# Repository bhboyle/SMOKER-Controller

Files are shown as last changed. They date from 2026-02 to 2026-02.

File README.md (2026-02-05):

# DIY Smoker Controller System

A dual-ESP32 based smart controller system for pellet or Gravity smokers, featuring a touchscreen display unit and WiFi-enabled web interface for remote monitoring and control. 

Some notes about the dual ESP32 design. I originally had planned to use just the display ESP32P4(with its ESP32-C6) however I found that the system lagged more than I was comfortable with and decided to add the ESP32-S3. This may have been my skills or something else. I also went with the ESP32-S3-N16R8 version for the web server allowing for a large filesystem to store smoker logs which I plan to use for "recipes." I also liked the OTA option for the web server given its going to be difficult to update once installed in the smokers housing. I don't expect to need to update the display ESP32-P4 now that it is only driving the display, fan and tach.

This system is not intended to less expensive than other options out in the aftermarket stores. Depending on where your buying the parts it would likely be around 80-100 dollars in parts assuming you have some of the essentials like screws and heat set inserts. With all the hardware testing I did it was notably more expensive than an existing product. However, now that it is done, I have exactly what I wanted, it is configurable and updatable in ways store bought options could never be. This has been a passion project that is now ready to be tested on my Masterbuilt Gravity smoker.

## ⚠️ Safety Warning

**🔥🔥This project involves controlling and working with fire. Use at your own risk.🔥🔥**

**IMPORTANT:**
- This software and design is provided as-is with no guarantees of safety or reliability
- You assume all responsibility for any damage, injury, or loss resulting from the use of this project
- Always follow proper fire safety protocols and never leave your smoker unattended
- Ensure your hardware setup meets all local electrical and fire safety codes
- The authors are not responsible for any accidents, fires, property damage, or injuries

**By using this project, you acknowledge these risks and agree to take full responsibility.**

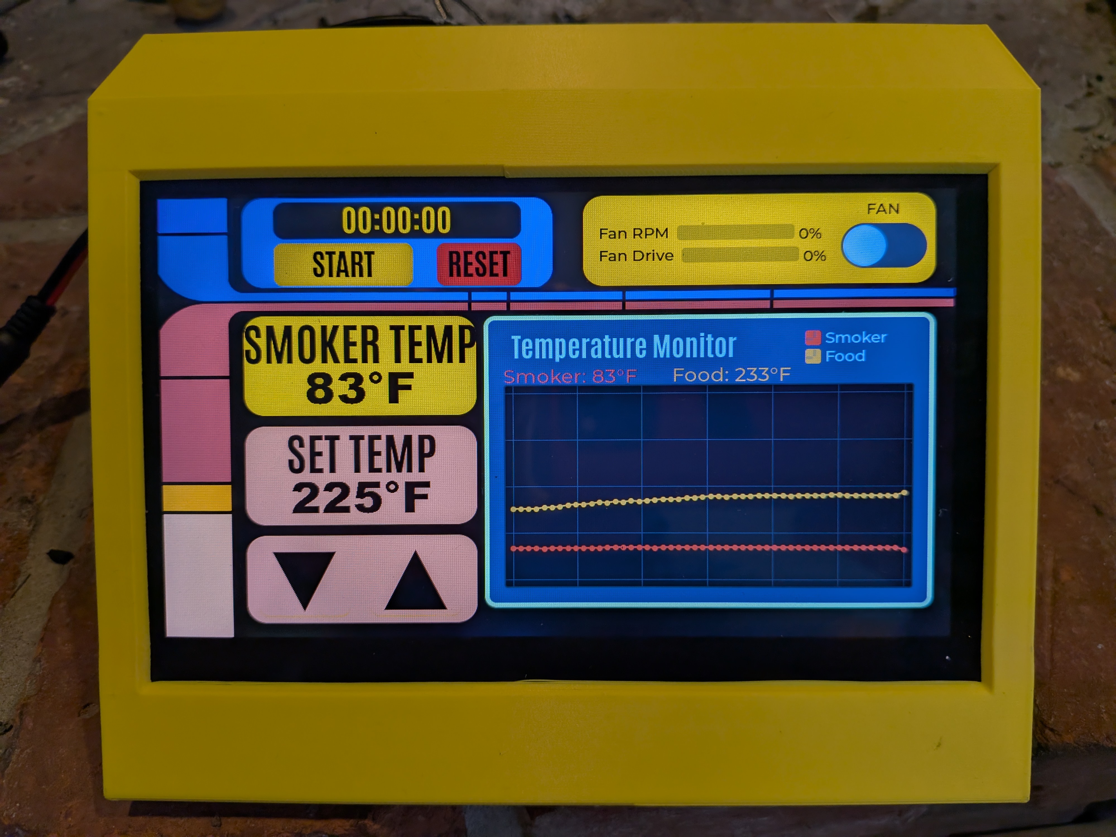
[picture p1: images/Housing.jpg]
Image of controller





## System Overview

This project consists of two ESP32 microcontrollers working together to provide comprehensive smoker monitoring and control:

```
┌─────────────────────────────────────────────────────────────────────────────┐
│                        SMOKER CONTROLLER SYSTEM                             │
├─────────────────────────────────────────────────────────────────────────────┤
│                                                                             │
│   ┌─────────────────────┐         UART           ┌─────────────────────┐    │
│   │    ESP32-P4         │◄──────────────────────►│    ESP32-S3         │    │
│   │  Display Controller │    (Bidirectional)     │    Web Server       │    │
│   └─────────────────────┘                        └─────────────────────┘    │
│            │                                              │                 │
│            │                                              │                 │
│            ▼                                              ▼                 │
│   ┌─────────────────────┐                        ┌─────────────────────┐    │
│   │ 1024x600 LCD        │                        │ WiFi / Web UI       │    │
│   │ Touchscreen         │                        │ MAX6675 Sensors     │    │
│   │ Fan PWM Control     │                        │ OTA Updates         │    │
│   │ PID Controller      │                        │ Temperature Sensing │    │
│   └─────────────────────┘                        └─────────────────────┘    │
│                                                                             │
└─────────────────────────────────────────────────────────────────────────────┘
```

### Build environment.
It is worth noting that I used the excelent [Arduinio Maker Workshop](https://github.com/thelastoutpostworkshop/arduino-maker-workshop) VSCode extension for these projects. Each one of the two projects included here includes the build profiles so assuming you use the same hardware you can comnpile it without any issues with libraries.

### ESP32-P4: Display Controller
**Location:** [DisplayControler/](DisplayControler/)

The display unit(JC1060P470) provides the physical user interface:
- 1024x600 LCD touchscreen with GT911 capacitive touch
- PID-based temperature control algorithm
- PWM fan control with RPM feedback
  - it is worth noting that the system does not have to drive a fan. With some minor changes this system could drive a servo instead of a fan to control an ball valve. This would allow you to control passive fire systems like other Gravity Smokers.
- Real-time temperature charting
- Cook timer functionality
- Safety watchdog (auto-disables fan if communication lost)
- [Ordered from here](https://www.aliexpress.com/p/tesla-landing/index.html?productId=1005009348846335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)

### ESP32-S3: Web Server
**Location:** [SmokerWebServer/](SmokerWebServer/)

The web server module handles connectivity and sensing:
- WiFi connectivity with AP fallback for setup
- Mobile-friendly web dashboard
- MAX6675 thermocouple interfaces (smoker + food probes)
- WebSocket for real-time updates
- REST API for integration
- OTA (Over-The-Air) firmware updates
- mDNS support (`smoker.local`)
- [Example here from Amazon](https://www.amazon.ca/HiLetgo-ESP32-S3-ESP32-S3-DevKit-Bluetooth-Development/dp/B0CDWXWXCG)

## Features

### Temperature Monitoring
- Dual K-type thermocouple inputs (smoker chamber + food probe)
- Calibration offsets (-50 to +50°F) stored in non-volatile memory
- 2-hour temperature history with graphing both on display and webpage
- Real-time updates via WebSocket (1-second refresh)

### Temperature Control
- PID algorithm for precise temperature maintenance
- Configurable PID parameters (Kp, Ki, Kd) from the webpage
- Fan-based airflow control with RPM feedback
- Target temperature range: 150-500°F

### User Interface
- **Local:** 1024x600 touchscreen with intuitive controls
- **LCARS** interface. I'm a Trekie so I use the Star Trek TNG LCARS as my inspiration for the user interface on the touch screen 
- **Remote:** Responsive web interface accessible from any device
- Both interfaces show:
  - Current smoker and food temperatures
  - Target temperature with adjustment controls
  - Fan status, RPM, and PWM percentage
  - Cook timer with start/stop/reset

### Safety Features
- Temperature watchdog: Fan auto-disables if no data received for 10 seconds
- PID output limits for controlled operation
- Visual "NO LINK" indicator on display when communication is lost with web server.

## Hardware Requirements

### Components List

| Component | Quantity | Purpose |
|---|---|---|
| [ESP32-P4 Development Board](https://www.aliexpress.com/p/tesla-landing/index.html?productId=1005009348846335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) | 1 | Display controller |
| [ESP32-S3-DevKitC-1 (N16R8)](https://www.amazon.ca/HiLetgo-ESP32-S3-ESP32-S3-DevKit-Bluetooth-Development/dp/B0CDWXWXCG) | 1 | Web server, WiFi, sensors |
| 1024x600 LCD (JD9165 driver) | 1 | Main display (Integrated) |
| GT911 Touch Controller | 1 | Touchscreen input (Integrated)|
| [MAX6675 Thermocouple Module](https://www.amazon.ca/dp/B0DDCGDLGJ?ref=ppx_yo2ov_dt_b_fed_asin_title)  | 2 | Temperature sensing |
| K-type Thermocouple | 1 | Smoker probe (Just use prone that came with the module) |
| [K-type Thermocouple](https://www.amazon.ca/dp/B0BJB1JZKQ) | 1 | food probe |
| 4-wire PWM Fan | 1 | Airflow control |
| [14pin .5mm FPC connector](https://www.amazon.ca/dp/B0CLH5FWKN?ref=ppx_yo2ov_dt_b_fed_asin_title&th=1) | 1 | communication to Web server |
| [Flexible flat cable](https://www.amazon.ca/dp/B07RWF4FF6?ref=ppx_yo2ov_dt_b_fed_asin_title) | 1 | connection with Web server |

### Pin Connections

#### ESP32-P4 (Display Controller)
| Function | GPIO |
|---|---|
| Fan PWM Output | 28 |
| Fan Tachometer Input | 29 |
| Serial TX (to S3) | 34 |
| Serial RX (from S3)  | 33 |

#### ESP32-S3 (Web Server)
| Function | GPIO |
|---|---|
| SPI CLK (MAX6675) | 12 |
| SPI MISO (MAX6675)  | 13 |
| Smoker Probe CS | 10 |
| Food Probe CS | 11 |
| Serial TX (to P4) | 17 |
| Serial RX (from P4) | 18 |

### Wiring Diagram

```
ESP32-S3                                ESP32-P4
┌─────────┐                            ┌─────────┐
│  GPIO17 ├───── TX ──────────────────►│ GPIO33  │ RX
│  GPIO18 │◄──── RX ───────────────────┤ GPIO34  │ TX
│         │                            │         │
│  GPIO12 ├──── CLK ──┐                │ GPIO28  ├──── PWM ────► Fan
│  GPIO13 ├──── MISO ─┤                │ GPIO29  │◄─── TACH ───┤
│  GPIO10 ├──── CS1 ──┼──► MAX6675s    └─────────┘
│  GPIO11 ├──── CS2 ──┘
│         │ 
└─────────┘ 

```

## Serial Communication Protocol

The two ESP32s communicate via UART using a simple text-based protocol:

### ESP32-S3 → ESP32-P4
```
TEMPS:smokerTemp,foodTemp              # Temperature readings (periodic)
CMD:SET_TEMP:225                       # Set target temperature
CMD:FAN:ON / CMD:FAN:OFF               # Fan control
CMD:TIMER:START / STOP / RESET         # Timer control
CMD:PID:Kp:Ki:Kd                       # Update PID parameters
CMD:GET_CONFIG                         # Request configuration
```

### ESP32-P4 → ESP32-S3
```
DATA:smokerTemp,foodTemp,setTemp,rpm,pwm,fanOn,timerMs,Kp,Ki,Kd
CONFIG:dispInterval,chartInterval,buttonHold,swapInterval,fadeDuration,Kp,Ki,Kd
```

## PID Tuning:
I used [this page](https://www.compuphase.com/electronics/reflowsolderprofiles.htm#_) to help me with the PID tuning. 
It help me know which numbers to change and how. I started with a P value of 20 and zero for both I and D. This worked fairly well but through iterative testing I settled on P=7 I=.01 and D=.2 Your setup may be different but the page above would help you alot. 

## Installation
I used the Arduino Maker Workshop plugin for VSCode so the Sketch.yaml file in both project folders contians the library data and versions so there should be no conflicts when building.

## Initial Setup

### WiFi Configuration

1. On first boot, the ESP32-S3 creates an access point:
   - **SSID:** `SmokerSetup`
   - **Password:** `smoker123`
   - **IP:** `192.168.4.1`

2. Connect to the network and open `http://192.168.4.1`

3. Enter your WiFi credentials and save

4. The device restarts and connects to your network

### Accessing the Web Interface

After WiFi setup:
- **mDNS:** `http://smoker.local`
- **IP Address:** Check serial monitor or router DHCP list

## Usage

### Local (Touchscreen)
- **Temperature:** Tap UP/DOWN to adjust target, display alternates between smoker and food temps
- **Fan:** Toggle ON/OFF switch
- **Timer:** START/STOP and RESET buttons

### Remote (Web Interface)
- Navigate to `http://smoker.local`
- All controls mirror the touchscreen interface
- View 2-hour temperature history chart
- Adjust calibration offsets in Settings
- Tune PID parameters if needed
- Record, edit and save smoking sessions in database
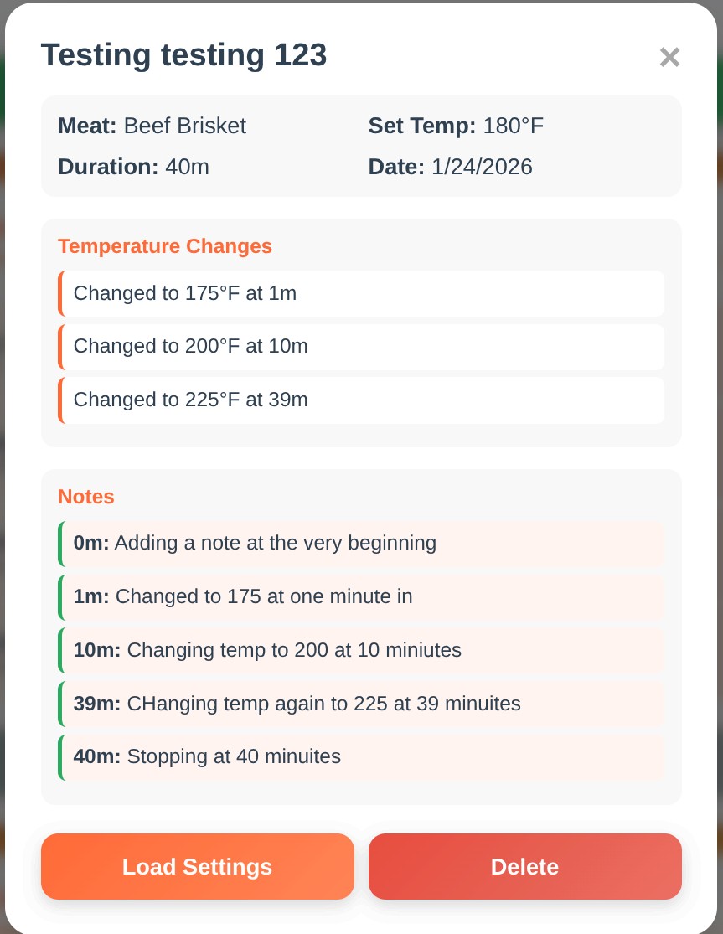
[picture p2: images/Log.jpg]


### OTA Updates
1. Navigate to `http://smoker.local/update`
2. Upload new firmware binary
3. Device restarts automatically

## API Reference

### REST Endpoints
| Endpoint | Method | Description |
|---|---|---|
| `/` | GET | Web dashboard |
| `/api/state` | GET | Current state (JSON) |
| `/api/command` | POST | Send command |
| `/api/calibration` | GET/POST | Calibration offsets  |
| `/wifi/status` | GET | WiFi status |
| `/wifi` | POST | Configure WiFi |
| `/update` | GET | OTA update page |

### WebSocket
Connect to `/ws` for real-time state updates at 1Hz.

## Project Structure

```
SMOKER Build/
├── README.md                              # This file
├── 5-Schematic/                           # Hardware schematics of display board
│   ├── 1_PWR.png
│   ├── 2_LCD.png
│   ├── 3_ESP32-P4.png
│   ├── 4_CONN.png
│   ├── 5_ESP32-C6.png
│   ├── 6_USB.png
│   └── 7_CODEC.png
├── DisplayControler/                       # ESP32-P4 Display Controller
│   ├── DisplayControler.ino
│   ├── pins_config.h
│   ├── style.h
│   ├── lv_conf.h
│   └── src/
│       ├── lcd/                           # LCD drivers
│       └── touch/                         # Touch drivers
└── SmokerWebServer/                       # ESP32-S3 Web Server
    ├── partitions.csv                     # ESP32 partition layout 
    ├── SmokerWebServer.ino
    ├── README.md
    └── (web interface files)
    
```

## Configuration Defaults

### PID Parameters
| Parameter | Default |
|---|---|
| Kp | 7.0 |
| Ki | 0.0 |
| Kd | 0.2 |

### Temperature Limits
| Setting | Value |
|---|---|
| Minimum | 150°F |
| Maximum | 500°F |
| Default | 225°F |

### Timing
| Setting | Default |
|---|---|
| Display Update | 500ms |
| Chart Update | 60 seconds |
| WebSocket Update | 1 second |
| Watchdog Timeout | 10 seconds |

## Troubleshooting

### Display shows "NO LINK"
- Check UART wiring between ESP32-P4 and ESP32-S3
- Verify TX connects to RX and vice versa
- Ensure both boards are powered

### Temperature shows -999
- Check MAX6675 wiring (CS, CLK, MISO)
- Verify thermocouple connections
- Check for open circuit in thermocouple

### Cannot connect to web interface
- Verify ESP32-S3 is connected to WiFi (check serial output)
- Try IP address instead of mDNS
- Ensure you're on the same network

### Fan not responding
- Check PWM wiring to GPIO 28 on ESP32-P4
- Verify fan receives proper power
- Check tachometer feedback wiring

## License

This project is licensed under the MIT License.

## Acknowledgments

- ESP32 Arduino Core developers
- LVGL graphics library team
- PID library developer
- AsyncWebServer library maintainers
- ElegantOTA for OTA updates
- Created with assistance from Claude (Anthropic)

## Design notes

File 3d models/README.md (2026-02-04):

I used a Bamblu labs P1S for my prints. I printed the housing on its back and required supports for the saids as well as the bottom of the display side. With out the supports the side tended to lean while being printed.

The template file is to be used to drill mounting holes if necessary.

The PCB for the second ESP32 the S3 and the MAX7765 among other things was fabricated on a perf board. The PCB mounting model is for attaching the two boards together. The perf board I used was [this one](https://www.amazon.ca/dp/B07Y3DVM1W?ref=ppx_yo2ov_dt_b_fed_asin_title&th=1).

I added some electrical tape on the under side of the retainer clips to act as padding. Not totally necessary but it seemed like a good idea to me.

The "Smoker Housing.f3d" file is the Fusion file for all compoments. With that you can make any changes you might need.

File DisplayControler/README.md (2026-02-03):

# Smoker Controller - Display Unit

An ESP32-P4 based touchscreen controller for monitoring and controlling a smoker. This unit provides the user interface with a 1024x600 LCD display and communicates with a separate ESP32-S3 web server module that handles temperature sensors and WiFi connectivity.

## Features

- **PID Temperature Control**: Maintains smoker temperature using a fan-based airflow control system
- **Dual Temperature Monitoring**: Displays both smoker chamber and food probe temperatures
- **Touchscreen Interface**: 1024x600 LCD with GT911 capacitive touch
- **Real-time Temperature Chart**: Graphical display of temperature history over time
- **Cook Timer**: Start/stop/reset timer for tracking cook duration
- **Fan Control**: Manual on/off control with RPM and drive percentage displays
- **Configurable Settings**: PID tuning parameters, display intervals, and UI settings stored in NVS (non-volatile storage)
- **Safety Watchdog**: Automatically disables fan if temperature data is not received within 10 seconds




## Hardware Requirements

### Display Controller (This Unit)
- **MCU**: ESP32-P4
- [Device was ordred from here](https://www.aliexpress.com/p/tesla-landing/index.html?productId=1005009348846335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)
- **Display**: 1024x600 LCD with JD9165 driver
- **Touch**: GT911 capacitive touch controller
- **Fan Output**: PWM on GPIO 28
- **Tachometer Input**: GPIO 29 (fan RPM feedback)
- **Serial Communication**: UART1 on GPIO 33 (RX) / GPIO 34 (TX)

### Web Server (Separate ESP32-S3 Module)
- Handles MAX6675 thermocouple interfaces
- Provides WiFi web interface
- Sends temperature data via serial: `TEMPS:smokerTemp,foodTemp`

## Pin Configuration

| Function | GPIO |
|---|---|
| LCD Reset | 27 |
| LCD Backlight  | 23 |
| Touch SDA | 7 |
| Touch SCL | 8 |
| Fan PWM | 28 |
| Fan Tachometer | 29 |
| Web Serial RX  | 33 |
| Web Serial TX  | 34 |

## Serial Protocol

### Messages FROM Web Server (ESP32-S3)
```
TEMPS:smokerTemp,foodTemp          # Temperature data (sent periodically)
CMD:SET_TEMP:225                   # Set target temperature
CMD:FAN:ON / CMD:FAN:OFF           # Control fan
CMD:TIMER:START/STOP/RESET         # Control timer
CMD:PID:Kp:Ki:Kd                   # Update PID tuning
CMD:DISPLAY_INT:500                # Set display update interval (ms)
CMD:CHART_INT:60000                # Set chart update interval (ms)
CMD:HOLD_TIME:5000                 # Button hold time before swap (ms)
CMD:SWAP_INT:2000                  # Container swap interval (ms)
CMD:FADE_DUR:100                   # Animation fade duration (ms)
CMD:GET_CONFIG                     # Request current configuration
```

### Messages TO Web Server (ESP32-S3)
```
DATA:smokerTemp,foodTemp,setTemp,rpm,pwm,fanOn,timerMs,Kp,Ki,Kd
CONFIG:dispInterval,chartInterval,buttonHold,swapInterval,fadeDuration,Kp,Ki,Kd
```

## Configuration Parameters

### PID Defaults
| Parameter | Default Value |
|---|---|
| Kp | 7.0 |
| Ki | 0.0 |
| Kd | 0.2 |

### Temperature Limits
| Setting | Value |
|---|---|
| Minimum Temp | 150°F |
| Maximum Temp | 500°F |
| Startup Temp | 225°F |

### Timing Defaults
| Setting | Default |
|---|---|
| Display Update | 500ms |
| Chart Update | 60000ms (1 min)  |
| Serial Update | 500ms |
| Watchdog Timeout | 10000ms (10 sec) |

## User Interface

The display is organized into several sections:

1. **Timer Section** (top-left): Displays elapsed cook time with START/STOP and RESET buttons
2. **Temperature Display** (left-center): Alternates between Actual Temp and Food Temp with cross-fade animation
3. **Set Temperature** (left-lower): Shows target temperature with UP/DOWN adjustment buttons
4. **Fan Control** (top-right): ON/OFF switch with RPM and Drive percentage bars
5. **Temperature Chart** (right): Real-time graph showing smoker (red) and food (orange) temperature trends

## Dependencies

- [LVGL](https://lvgl.io/) - Light and Versatile Graphics Library (v9.x)
- [PID_v1](https://github.com/br3ttb/Arduino-PID-Library) - Arduino PID Library
- ESP32 Arduino Core with Preferences library

## Building

This project is designed for the Arduino IDE or VSCode with the Arduino Maker Workshop with ESP32-P4 board support.

1. Install ESP32 board support (ESP32-P4 variant)
2. Install required libraries (LVGL, PID_v1)
3. Configure `lv_conf.h` for your display settings
4. Upload to ESP32-P4
5. Thsi display is configured for the resolution of the device I ordered. If your has a different resolution you will have to adjust things considerably.

## File Structure

```
DisplayControler/
├── DisplayControler.ino   # Main application
├── pins_config.h                          # GPIO pin definitions
├── style.h                                # LVGL style definitions
├── lv_conf.h                              # LVGL configuration
├── src/
│   ├── lcd/
│   │   ├── jd9165_lcd.cpp/.h              # LCD driver wrapper
│   │   └── esp_lcd_jd9165.c/.h            # Low-level LCD driver
│   └── touch/
│       ├── gt911_touch.cpp/.h             # Touch driver wrapper
│       ├── esp_lcd_touch_gt911.c/.h       # GT911 touch driver
│       └── esp_lcd_touch.c/.h             # Touch abstraction layer
└── *.c                                    # Custom fonts (Antonio, Arial)
```

## Safety Features

- **Temperature Watchdog**: If no temperature data is received from the ESP32-S3 for 10 seconds, the fan is automatically disabled to prevent uncontrolled heating
- **PID Output Limits**: Maximum fan PWM is capped at 255 but could be reduced in the code if there is a need to set lower limits. For example if you used a much more powerful fan you may want to reduce its upper limit.
- **Connection Status**: Display shows "NO LINK" when communication with the temperature sensor module is lost

## License

This project is for personal/educational use.

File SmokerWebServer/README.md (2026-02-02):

# Smoker Web Server - ESP32-S3

A web-based control and monitoring system for a pellet smoker, running on ESP32-S3. This firmware provides a mobile-friendly web interface for monitoring and controlling your smoker remotely.




## Overview

This project is the web server component of a two-board smoker controller system:
- **ESP32-S3** (this project): Handles WiFi, web interface, and temperature sensing
- **ESP32-P4** (display controller): Handles the physical display, fan control, and PID regulation

The ESP32-S3 reads temperatures from MAX6675 thermocouple sensors and sends them to the display controller, while also providing a responsive web dashboard for remote monitoring and control.

## Features

- **Real-time Monitoring**
  - Smoker temperature display
  - Food probe temperature display
  - Fan RPM and PWM output visualization
  - Cook timer with start/stop/reset controls
  - 2-hour temperature history chart

- **Remote Control**
  - Set target temperature
  - Toggle fan on/off
  - Adjust PID parameters (Kp, Ki, Kd)
  - Timer controls

- **Temperature Calibration**
  - Adjustable offset for smoker probe (-50 to +50°F)
  - Adjustable offset for food probe (-50 to +50°F)
  - Calibration values stored in NVram (persistent across power cycles)

- **Connectivity**
  - WiFi with AP fallback mode for initial setup
  - mDNS support (access via `smoker.local`)
  - WebSocket for real-time updates (1-second refresh)
  - REST API for integration

- **System**
  - OTA (Over-The-Air) firmware updates via ElegantOTA
  - Persistent settings stored in NVram
  - Mobile-friendly responsive web design

## Hardware Requirements

### Main Components
- **ESP32-S3-DevKitC-1** (N16R8 configuration)
  - 16MB Flash
  - 8MB PSRAM
- **2x MAX6675** thermocouple amplifier modules
- **K-type thermocouples** for smoker and food probes
- **ESP32-P4** display controller (separate board)

### Pin Configuration

| Function | GPIO Pin |
|---|---|
| SPI CLK (MAX6675)  | GPIO 12  |
| SPI MISO (MAX6675) | GPIO 13  |
| Smoker Probe CS | GPIO 10  | 
| Food Probe CS | GPIO 11  |
| Controller TX | GPIO 17  |
| Controller RX | GPIO 18  |

## Installation

### Building with Arduino IDE
1. Install ESP32 board support via Board Manager
2. Select "ESP32S3 Dev Module" as the board
3. Configure Flash Size: 16MB
4. Open `SmokerWebServer.ino` and upload

## Initial Setup

### WiFi Configuration

On first boot (or when no WiFi credentials are stored), the ESP32-S3 creates an access point:

| Setting | Value |
|---|---|
| SSID | `SmokerSetup` |
| Password | `smoker123` |
| IP Address | `192.168.4.1` |

1. Connect to the `SmokerSetup` WiFi network
2. Open a browser and navigate to `http://192.168.4.1`
3. Expand the "WiFi Settings" section
4. Enter your WiFi credentials and hostname
5. Click "Save & Connect"

The device will restart and connect to your network.

### Accessing the Dashboard

After WiFi configuration:
- **mDNS**: `http://smoker.local` (or your custom hostname)
- **IP Address**: Check your router or serial monitor for the assigned IP

## Web Interface

### Temperature Display
Shows current readings for:
- **Smoker**: Internal smoker temperature
- **Food**: Food probe temperature
- **Set Temp**: Target temperature

### Controls
- **Set Temperature**: Use arrow buttons to adjust, then click "Set Temp"
- **Fan Control**: Toggle switch to enable/disable the fan
- **RPM/PWM Bars**: Visual indicators of fan speed and duty cycle

### Timer
- **Start/Stop**: Toggle the cook timer
- **Reset**: Reset timer to 00:00:00

### Temperature History
A 2-hour rolling chart showing smoker and food temperatures, updated every 2 minutes.

### Advanced Settings

#### Temperature Calibration
Adjust probe offsets to correct for sensor inaccuracies:
- **Positive values**: Add degrees (if sensor reads low)
- **Negative values**: Subtract degrees (if sensor reads high)
- Range: -50°F to +50°F
- Values are saved to NVram and persist across reboots

#### PID Settings
Fine-tune the temperature control algorithm:
- **Kp**: Proportional gain (default: 7.0)
- **Ki**: Integral gain (default: 0.0)
- **Kd**: Derivative gain (default: 0.2)

### WiFi Settings
Change WiFi network or hostname without reflashing.

## API Reference

### REST Endpoints

| Endpoint | Method | Description |
|---|---|---|
| `/` | GET | Main web dashboard |
| `/api/state` | GET | Current smoker state (JSON)  |
| `/api/command` | POST | Send command to controller |
| `/api/calibration` | GET | Get calibration offsets |
| `/api/calibration` | POST | Set calibration offsets |
| `/wifi/status` | GET | WiFi connection status | 
| `/wifi` | POST | Configure WiFi settings |
| `/update` | GET | OTA update page (ElegantOTA) |

### WebSocket

Connect to `/ws` for real-time state updates.

**State JSON Format:**
```json
{
  "controllerConnected": true,
  "smokerTemp": 225,
  "foodTemp": 145,
  "setTemp": 225,
  "rpm": 1500,
  "pwm": 128,
  "fanOn": true,
  "timerMs": 3600000,
  "Kp": 7.0,
  "Ki": 0.0,
  "Kd": 0.2,
  "smokerOffset": 0,
  "foodOffset": -5,
  "smokerHistory": [220, 222, 225, ...],
  "foodHistory": [140, 142, 145, ...],
  "historyCount": 30
}
```

### Command Format

Send commands via WebSocket or POST to `/api/command`:
```json
{"command": "SET_TEMP:250"}
{"command": "FAN:ON"}
{"command": "FAN:OFF"}
{"command": "TIMER:START"}
{"command": "TIMER:RESET"}
{"command": "PID:7.0:0.0:0.2"}
{"command": "GET_CONFIG"}
```

## Serial Protocol

Communication with the ESP32-P4 display controller:

| Direction | Format | Example |
|---|---|---|
| To Controller | `CMD:command` | `CMD:SET_TEMP:250` |
| To Controller | `TEMPS:smoker,food` | `TEMPS:225,145` |
| From Controller | `DATA:s,f,set,rpm,pwm,fan,timer,Kp,Ki,Kd` | `DATA:-1,-1,225,1500,128,1,3600000,7.0,0.0,0.2` |

**Note:** The display controller sends `-1` for temperature values since the ESP32-S3 reads them locally.

## Partition Layout

Custom partition table optimized for OTA updates and data storage:

| Partition | Size  | Purpose |
|---|---|---|
| NVS | 24KB  | WiFi credentials, calibration, preferences |
| PHY_INIT  | 4KB | WiFi calibration data |
| OTA Data  | 8KB | Tracks active app partition |
| App0 | 3MB | Primary application |
| App1 | 3MB | OTA update partition |
| LittleFS  | 9.8MB | Future database storage |
| Coredump  | 64KB  | Crash debugging |

## OTA Updates

1. Navigate to `http://smoker.local/update`
2. Select the new firmware `.bin` file
3. Click "Update"
4. Wait for the device to restart

## Troubleshooting

### Cannot connect to WiFi
- Ensure credentials are correct
- Check if the network is 2.4GHz (ESP32 doesn't support 5GHz)
- Try resetting by erasing flash and reconfiguring

### Temperature reads -999
- Check thermocouple connections
- Verify MAX6675 wiring (CS, CLK, MISO pins)
- Ensure thermocouples are not open circuit

### Web interface not updating
- Check WebSocket connection status
- Verify the ESP32 is connected to WiFi
- Try refreshing the page

### Controller shows "Not Connected"
- Check serial connection between ESP32-S3 and P4
- Verify TX/RX pins are correctly wired (TX to RX, RX to TX)
- Ensure both boards are powered

## Dependencies

- [ESPAsyncWebServer](https://github.com/me-no-dev/ESPAsyncWebServer)
- [AsyncTCP](https://github.com/me-no-dev/AsyncTCP)
- [ArduinoJson](https://arduinojson.org/)
- [ElegantOTA](https://github.com/ayushsharma82/ElegantOTA)
- ESP32 Preferences library (built-in)

## Contributing

Contributions are welcome! Please feel free to submit a Pull Request.

## License

This project is licensed under the MIT License - see the [LICENSE](LICENSE) file for details.

## Author

Created with assistance from Claude (Anthropic)

## Acknowledgments

- ESP32 Arduino Core developers
- AsyncWebServer library maintainers
- ElegantOTA for simple OTA updates

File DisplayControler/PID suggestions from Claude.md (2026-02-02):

PID Tuning Suggestions for Smoker Temperature Control
Based on your current values (P=7, I=0, D=0.2), here are some suggestions:

Current Issues Analysis
I=0 (No Integral): Without an integral term, you'll likely have steady-state error - the temperature will settle somewhere near but not exactly at your setpoint. This makes it hard to maintain temperature within 5°F.

D=0.2 is relatively low: For thermal systems which respond slowly, a higher derivative term can help anticipate changes and reduce overshoot.

Recommended Starting Points
Option 1: Conservative Tuning (Minimal Overshoot Priority)

P = 5-6    (slightly lower to reduce overshoot)
I = 0.01-0.05  (small value to eliminate steady-state error)
D = 0.5-1.0    (higher to dampen oscillations)
Option 2: Responsive Tuning (Faster to Setpoint)

P = 7-8    (keep similar)
I = 0.02-0.1   (moderate integral)
D = 1.0-2.0    (more aggressive dampening)
Key Principles for Thermal Systems
Parameter	Effect	Smoker Considerations
P (Proportional)	Determines response strength	Too high = overshoot; too low = slow response
I (Integral)	Eliminates steady-state error	Essential for holding ±5°F; start very small
D (Derivative)	Dampens oscillations	Thermal mass means changes are slow; higher D helps
Tuning Process
Add a small I term first (try 0.02) - this will help eliminate the offset between actual and target temp

Increase D (try 0.5-1.0) - this will help prevent overshoot as you approach setpoint

Adjust P if needed - if you still overshoot, reduce P slightly

Watch for integral windup - if your code doesn't limit integral accumulation, the I term can cause large overshoots after long periods below setpoint

Suggested Starting Point

P = 6
I = 0.03
D = 0.8
This should give you smooth approach to setpoint with minimal overshoot, and the integral term will work to keep you within your ±5°F band.

Would you like me to look at your actual PID implementation code to see if there are any other factors (like integral windup protection, output clamping, or sample rate) that might affect tuning?

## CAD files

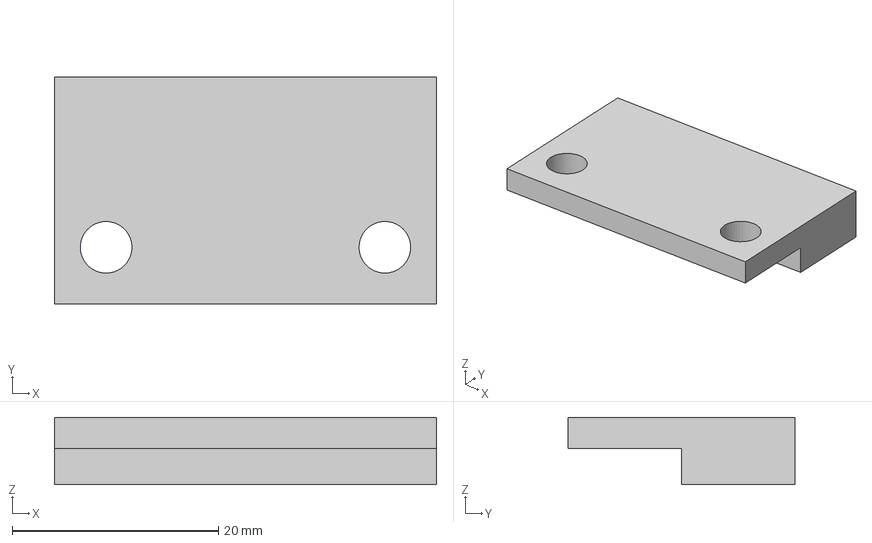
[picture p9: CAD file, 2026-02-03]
3d models/Small Clip.3mf
37.0 x 22.0 x 6.50 mm

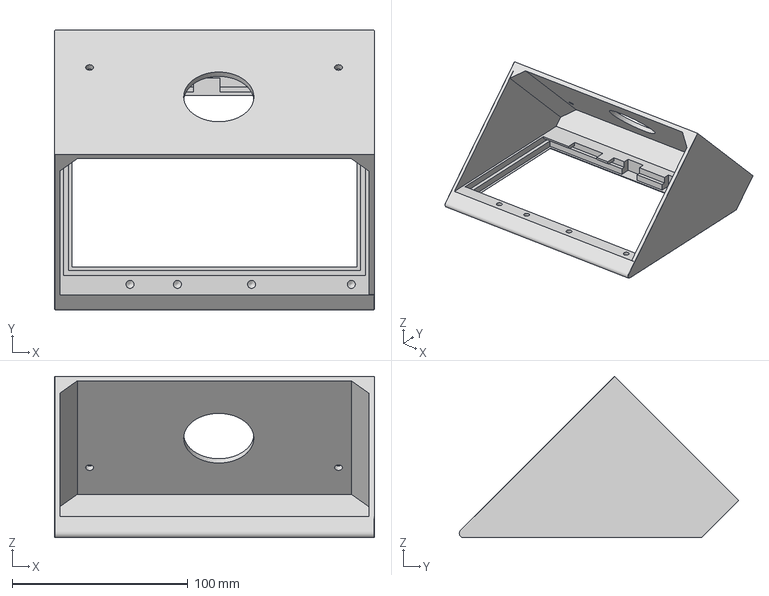
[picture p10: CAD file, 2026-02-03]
3d models/Housing.3mf
182.2 x 159.2 x 91.9 mm

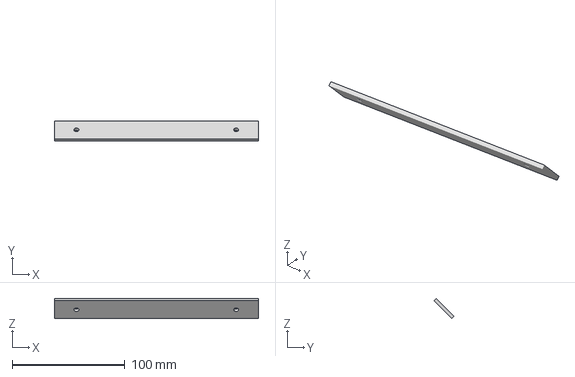
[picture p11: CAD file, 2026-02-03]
3d models/Template.3mf
180.9 x 18.0 x 18.0 mm

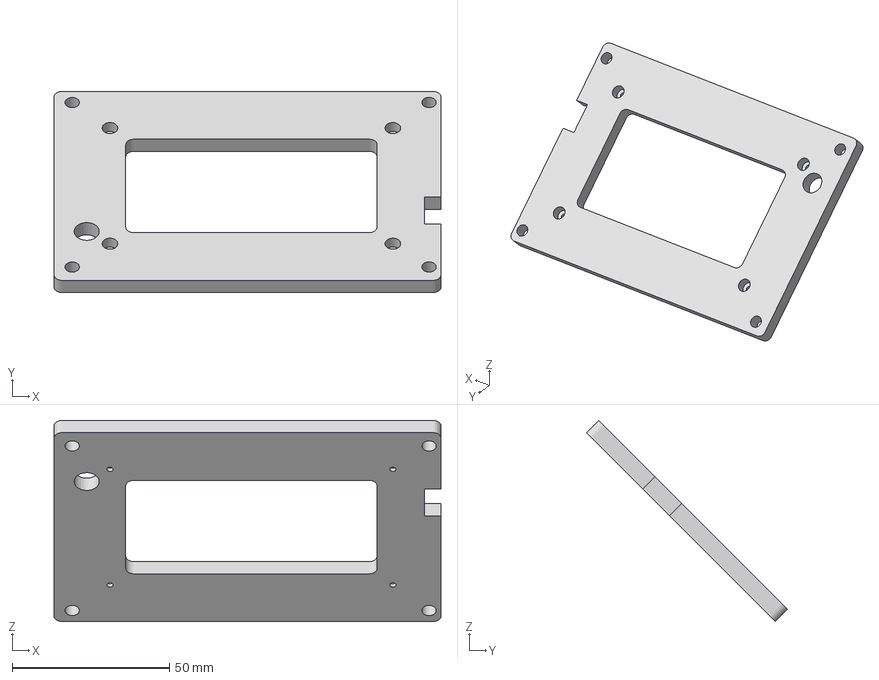
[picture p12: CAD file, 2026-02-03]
3d models/PCB Mount.3mf
123.1 x 64.0 x 64.0 mm

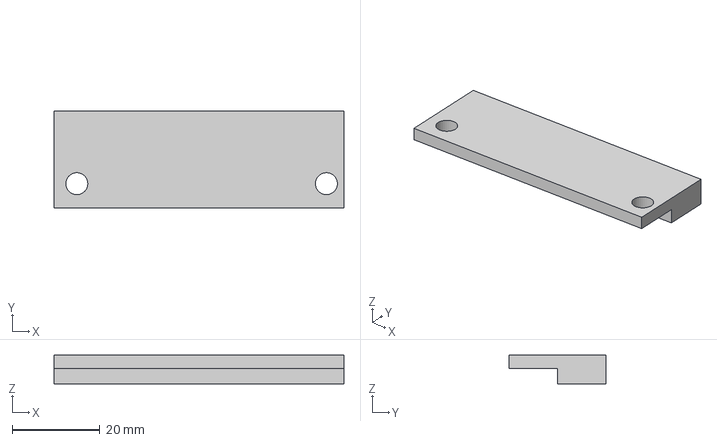
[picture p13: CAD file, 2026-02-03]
3d models/Large Clip.3mf
66.0 x 22.0 x 6.50 mm

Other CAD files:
3d models/Smoker Housing.f3d

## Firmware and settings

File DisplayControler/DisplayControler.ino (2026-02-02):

#include <lvgl.h>
#include <Arduino.h>
#include <PID_v1.h>
#include <Preferences.h>
#include "esp_timer.h"
#include "style.h"
#include "pins_config.h"
#include "src/lcd/jd9165_lcd.h"
#include "src/touch/gt911_touch.h"

// Definitions
#define PWM_PIN 28           // this is the pin that is used to drive the FAN via PID
#define TACH_PIN 29          // This is the imput pin for the fan Tac
#define LowTemp 150          // the lowest PID controlled temperature
#define MaxTemp 500          // Maximum PID controled temperature
#define MAX_PID_OUTPUT 255   // Limit max fan speed for safety
#define StartupTemp 225      // set the start up temperature
#define TACH_SAMPLE_TIME 500 // the frequincy to check and update the fan tacometer
#define default_P 7.0        // Defaule PID value for P if nothing is in the NVram
#define default_I 0.0        // Defaule PID value for I if nothing is in the NVram
#define default_D 0.2        // Defaule PID value for D if nothing is in the NVram

// Temperature data from ESP32-S3 Web Server
#define TEMP_WATCHDOG_TIMEOUT 10000  // 10 seconds - shutdown if no temp data received

// Serial Communication Settings
#define ENABLE_USB_SERIAL_DEBUG false // Set to false to disable USB serial debug output
#define WEB_SERIAL_RX 33             // GPIO 33 for Web Server RX
#define WEB_SERIAL_TX 34             // GPIO 34 for Web Server TX
#define SERIAL_BAUD 115200
#define SERIAL_UPDATE_INTERVAL 500 // Send data every 500ms
#define SERIAL_BUFFER_SIZE 128

// Preferences namespace
#define PREFS_NAMESPACE "smoker"

// Serial communication variables
HardwareSerial WebSerial(1); // UART1 for web server communication on GPIO 33/34
unsigned long lastSerialUpdateTime = 0;
char serialBuffer[SERIAL_BUFFER_SIZE];
int serialBufferIndex = 0;

// Temperature data received from ESP32-S3 Web Server
int receivedSmokerTemp = -999;    // -999 indicates no valid data
int receivedFoodTemp = -999;      // -999 indicates no valid data
unsigned long lastTempReceiveTime = 0;  // Timestamp of last TEMPS message
bool tempSensorConnected = false;       // Connection status for display

jd9165_lcd lcd = jd9165_lcd(LCD_RST);
gt911_touch touch = gt911_touch(TP_I2C_SDA, TP_I2C_SCL, TP_RST, TP_INT);

lv_display_t *disp_drv;
static uint32_t *buf;
static uint32_t *buf1;

lv_obj_t *timeLabel = nullptr;
lv_obj_t *btnUP = nullptr;
lv_obj_t *btnDOWN = nullptr;
lv_obj_t *lblSetTemp = nullptr;
lv_obj_t *lblActualTemp = nullptr;
lv_obj_t *btnSSTmr = nullptr;
lv_obj_t *btnTimerReset = nullptr;
lv_obj_t *fanSwitch = nullptr;
lv_obj_t *driveBar = nullptr;
lv_obj_t *drivePercent = nullptr;
lv_obj_t *rpmLabel = nullptr;
lv_obj_t *rpmBar = nullptr;
lv_obj_t *rpmPercent = nullptr;
lv_obj_t *lblFoodTemp = nullptr;
lv_obj_t *tempChart = nullptr;
lv_chart_series_t *smokerSeries = nullptr;
lv_chart_series_t *foodSeries = nullptr;
lv_obj_t *currentSmokerTemp = nullptr;
lv_obj_t *currentFoodTemp = nullptr;

// Global container pointers for alternating display
lv_obj_t *ActualTempContainer = nullptr;
lv_obj_t *FoodTempContainer = nullptr;

lv_timer_t *time_Timer = NULL;
lv_timer_t *containerSwapTimer = NULL;

static lv_style_t styleUP;
static lv_style_t styleDate;
static lv_style_t styleDaysOfWeek;
static lv_style_t styleTime;
static lv_style_t styleSetTemp;
static lv_style_t styleSSTmr;
static lv_style_t styleTimerReset;

static unsigned long timerStartTime = 0; // When timer started/resumed
static unsigned long elapsedTime = 0;    // Total elapsed time in ms
static bool timerRunning = false;        // Track if timer is running

// ----------------> Global Variables
char timeHour[3] = "00";
char timeMin[3] = "00";
char timeSec[3];
String _Time = "";
int SetTemp;
int ActualTemp;                            // variable to hold Smoker temperature
double Kp = default_P;                     // PID "P" variable
double Ki = default_I;                     // PID "I" variable
double Kd = default_D;                     // PID "D" variable
double Input, Output, Setpoint = 225.0;    // Vasiable for the PID contorller
unsigned long lastDisplayUpdateTime;       // used to treck the last time the display was updated
unsigned long displayUpdateInterval = 500; // the intervale that the display is updated (configurable)
unsigned long chartUpdateInterval = 60000; // Chart updates every 60 seconds (configurable)
unsigned long lastChartUpdateTime = 0;     // Track last chart update
bool fanEnabled = false;                   // used to track if the smoker is active or not
volatile unsigned long tachPulseCount = 0; // variable for counting the fan pulses for teh tachometer
volatile int lastTachState = HIGH;         // track previous tach pin state for edge detection
esp_timer_handle_t tachTimerHandle = NULL; // hardware timer for tach polling
int globalRPM;                             // main variable for holding the realtime RPM
// Timing variables for container swap logic
unsigned long lastButtonPressTime = 0;
bool showingActualTemp = true;       // Track which container is currently visible
unsigned long buttonHoldTime = 5000; // Time after button press before swapping (configurable)
unsigned long swapInterval = 2000;   // Time between container swaps (configurable)
int fadeDuration = 100;              // Animation duration in milliseconds (configurable)

// --------------> Object instanciations
Preferences preferences;
PID myPID(&Input, &Output, &Setpoint, Kp, Ki, Kd, DIRECT);

// --------------> Preferences Functions
void saveSettingsToEEPROM()
{
  preferences.begin(PREFS_NAMESPACE, false); // Open in read-write mode
  preferences.putDouble("Kp", Kp);
  preferences.putDouble("Ki", Ki);
  preferences.putDouble("Kd", Kd);
  preferences.putULong("dispInterval", displayUpdateInterval);
  preferences.putULong("chartInterval", chartUpdateInterval);
  preferences.putULong("buttonHold", buttonHoldTime);
  preferences.putULong("swapInterval", swapInterval);
  preferences.putInt("fadeDuration", fadeDuration);
  preferences.end();
} // end of Save Settings to EEPROM function

void loadSettingsFromEEPROM()
{
  preferences.begin(PREFS_NAMESPACE, true); // Open in read-only mode

  // Check if preferences exist by checking for a key
  if (preferences.isKey("Kp"))
  {
    Kp = preferences.getDouble("Kp", default_P);
    Ki = preferences.getDouble("Ki", default_I);
    Kd = preferences.getDouble("Kd", default_D);
    displayUpdateInterval = preferences.getULong("dispInterval", 500);
    chartUpdateInterval = preferences.getULong("chartInterval", 60000);
    buttonHoldTime = preferences.getULong("buttonHold", 5000);
    swapInterval = preferences.getULong("swapInterval", 2000);
    fadeDuration = preferences.getInt("fadeDuration", 100);

    // Update PID with loaded values
    myPID.SetTunings(Kp, Ki, Kd);
  }
  // If preferences don't exist, keep default values

  preferences.end();
} // end of load settings from EEPROM function

// --------------> Serial Communication Functions
void sendSerialData()
{
  // Format: DATA:smokerTemp,foodTemp,setTemp,rpm,pwm,fanOn,timerMs,Kp,Ki,Kd
  unsigned long currentElapsed = elapsedTime;
  if (timerRunning)
  {
    currentElapsed = elapsedTime + (millis() - timerStartTime);
  }

  // Use temperature data received from ESP32-S3 Web Server
  int smokerTemp = receivedSmokerTemp;
  int foodTemp = receivedFoodTemp;

  // Send to Web Server via hardware serial (GPIO 33/34)
  WebSerial.print("DATA:");
  // Send -1 for error conditions instead of -999 for cleaner protocol
  WebSerial.print(smokerTemp == -999 ? -1 : smokerTemp);
  WebSerial.print(",");
  WebSerial.print(foodTemp == -999 ? -1 : foodTemp);
  WebSerial.print(",");
  WebSerial.print(SetTemp);
  WebSerial.print(",");
  WebSerial.print(globalRPM);
  WebSerial.print(",");
  WebSerial.print((int)Output);
  WebSerial.print(",");
  WebSerial.print(fanEnabled ? 1 : 0);
  WebSerial.print(",");
  WebSerial.print(currentElapsed);
  WebSerial.print(",");
  WebSerial.print(Kp, 2);
  WebSerial.print(",");
  WebSerial.print(Ki, 2);
  WebSerial.print(",");
  WebSerial.println(Kd, 2);

  // Optionally duplicate to USB serial for debugging
  #if ENABLE_USB_SERIAL_DEBUG
  Serial.print("DATA:");
  Serial.print(smokerTemp == -999 ? -1 : smokerTemp);
  Serial.print(",");
  Serial.print(foodTemp == -999 ? -1 : foodTemp);
  Serial.print(",");
  Serial.print(SetTemp);
  Serial.print(",");
  Serial.print(globalRPM);
  Serial.print(",");
  Serial.print((int)Output);
  Serial.print(",");
  Serial.print(fanEnabled ? 1 : 0);
  Serial.print(",");
  Serial.print(currentElapsed);
  Serial.print(",");
  Serial.print(Kp, 2);
  Serial.print(",");
  Serial.print(Ki, 2);
  Serial.print(",");
  Serial.println(Kd, 2);
  #endif
} // end of Send Serial Data function 

// handles srial commands and data sent from the web server 
void processSerialCommand(char *cmd)
{
  // Parse incoming messages from Web Server ESP32
  // Format: CMD:COMMAND:VALUE or TEMPS:smokerTemp,foodTemp

  // Handle temperature data from ESP32-S3
  if (strncmp(cmd, "TEMPS:", 6) == 0)
  {
    char *tempData = cmd + 6;
    char *token = strtok(tempData, ",");
    if (token != NULL)
    {
      receivedSmokerTemp = atoi(token);
      token = strtok(NULL, ",");
      if (token != NULL)
      {
        receivedFoodTemp = atoi(token);
      }
    }
    lastTempReceiveTime = millis();
    tempSensorConnected = true;

    #if ENABLE_USB_SERIAL_DEBUG
    Serial.print("RX TEMPS: Smoker=");
    Serial.print(receivedSmokerTemp);
    Serial.print(", Food=");
    Serial.println(receivedFoodTemp);
    #endif
    return;
  }

  // Handle CMD messages
  if (strncmp(cmd, "CMD:", 4) != 0)
    return;

  char *command = cmd + 4;

  if (strncmp(command, "SET_TEMP:", 9) == 0)
  {
    int temp = atoi(command + 9);
    if (temp >= LowTemp && temp <= MaxTemp)
    {
      SetTemp = temp;
      Setpoint = temp;
      lv_label_set_text(lblSetTemp, ((String)SetTemp + "°F").c_str());
    }
  }
  else if (strncmp(command, "FAN:", 4) == 0)
  {
    if (strcmp(command + 4, "ON") == 0)
    {
      fanEnabled = true;
      myPID.SetMode(AUTOMATIC);
      // Update UI switch state
      if (fanSwitch)
        lv_obj_add_state(fanSwitch, LV_STATE_CHECKED);
    }
    else if (strcmp(command + 4, "OFF") == 0)
    {
      fanEnabled = false;
      analogWrite(PWM_PIN, 0);
      Output = 0;
      myPID.SetMode(MANUAL);
      // Update UI switch state
      if (fanSwitch)
        lv_obj_clear_state(fanSwitch, LV_STATE_CHECKED);
    }
  }
  else if (strncmp(command, "TIMER:", 6) == 0)
  {
    if (strcmp(command + 6, "START") == 0)
    {
      if (elapsedTime == 0 && !timerRunning)
        startTimer();
      else
        resumeTimer();
      // Update button text to STOP
      if (btnSSTmr)
      {
        lv_obj_t *label = lv_obj_get_child(btnSSTmr, 0);
        if (label)
          lv_label_set_text(label, "STOP");
      }
    }
    else if (strcmp(command + 6, "STOP") == 0)
    {
      pauseTimer();
      // Update button text to START
      if (btnSSTmr)
      {
        lv_obj_t *label = lv_obj_get_child(btnSSTmr, 0);
        if (label)
          lv_label_set_text(label, "START");
      }
    }
    else if (strcmp(command + 6, "RESET") == 0)
    {
      resetTimer();
    }
  }
  else if (strncmp(command, "PID:", 4) == 0)
  {
    // Format: CMD:PID:Kp:Ki:Kd
    char *pidValues = command + 4;
    char *token = strtok(pidValues, ":");
    if (token)
      Kp = atof(token);
    token = strtok(NULL, ":");
    if (token)
      Ki = atof(token);
    token = strtok(NULL, ":");
    if (token)
      Kd = atof(token);
    myPID.SetTunings(Kp, Ki, Kd);
    saveSettingsToEEPROM();
  }
  else if (strncmp(command, "DISPLAY_INT:", 12) == 0)
  {
    displayUpdateInterval = atol(command + 12);
    saveSettingsToEEPROM();
  }
  else if (strncmp(command, "CHART_INT:", 10) == 0)
  {
    chartUpdateInterval = atol(command + 10);
    saveSettingsToEEPROM();
  }
  else if (strncmp(command, "HOLD_TIME:", 10) == 0)
  {
    buttonHoldTime = atol(command + 10);
    saveSettingsToEEPROM();
  }
  else if (strncmp(command, "SWAP_INT:", 9) == 0)
  {
    swapInterval = atol(command + 9);
    lv_timer_set_period(containerSwapTimer, swapInterval);
    saveSettingsToEEPROM();
  }
  else if (strncmp(command, "FADE_DUR:", 9) == 0)
  {
    fadeDuration = atoi(command + 9);
    saveSettingsToEEPROM();
  }
  else if (strcmp(command, "GET_CONFIG") == 0)
  {
    // Send current configuration to Web Server
    WebSerial.print("CONFIG:");
    WebSerial.print(displayUpdateInterval);
    WebSerial.print(",");
    WebSerial.print(chartUpdateInterval);
    WebSerial.print(",");
    WebSerial.print(buttonHoldTime);
    WebSerial.print(",");
    WebSerial.print(swapInterval);
    WebSerial.print(",");
    WebSerial.print(fadeDuration);
    WebSerial.print(",");
    WebSerial.print(Kp, 2);
    WebSerial.print(",");
    WebSerial.print(Ki, 2);
    WebSerial.print(",");
    WebSerial.println(Kd, 2);
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
void loop()
{
  lv_tick_inc(5);
  lv_timer_handler();
  updateDisplay();

  // Handle serial communication
  checkSerialInput();

  // Send data to Web Server ESP32 at regular intervals
  if ((millis() - lastSerialUpdateTime) > SERIAL_UPDATE_INTERVAL)
  {
    sendSerialData();
    lastSerialUpdateTime = millis();
  }

  delay(5);
} // end of Loop Function

// start up update display function
// This function updates the display regularly
// with state changes and variable changes
// this is also where I will manage the PID controlloer if it is on
void updateDisplay()
{
  if ((millis() - lastDisplayUpdateTime) > displayUpdateInterval)
  {
    // ============ TEMPERATURE WATCHDOG CHECK ============
    // Check if we've received temperature data recently from ESP32-S3
    if (lastTempReceiveTime > 0 && (millis() - lastTempReceiveTime) > TEMP_WATCHDOG_TIMEOUT)
    {
      // No temperature data received within timeout - SAFETY SHUTDOWN
      tempSensorConnected = false;

      // Force disable PID and fan for safety
      if (fanEnabled == true)
      {
        fanEnabled = false;
        analogWrite(PWM_PIN, 0);
        Output = 0;
        myPID.SetMode(MANUAL);

        // Update UI switch state
        if (fanSwitch)
          lv_obj_clear_state(fanSwitch, LV_STATE_CHECKED);

        #if ENABLE_USB_SERIAL_DEBUG
        Serial.println("WATCHDOG: Temperature sensor timeout - FAN DISABLED FOR SAFETY!");
        #endif
      }
    }
    else if (lastTempReceiveTime > 0)
    {
      tempSensorConnected = true;
    }

    // Handle PID control if active (only if temp sensor connected)
    if (fanEnabled == true && tempSensorConnected)
    {
      myPID.SetMode(AUTOMATIC);
      myPID.Compute();
      analogWrite(PWM_PIN, Output);
    }
    else
    {
      analogWrite(PWM_PIN, 0);
      Output = 0;
      myPID.SetMode(MANUAL);
    }

    // update the fan drive percent bar
    int speedPercent = map(Output, 0, 255, 0, 100);            // convert current output value to a percent
    lv_bar_set_value(driveBar, speedPercent, LV_ANIM_ON);      // display it on the bar
    lv_label_set_text_fmt(drivePercent, "%d%%", speedPercent); // and the text

    // Use temperature data received from ESP32-S3 Web Server
    int smokerTemp = receivedSmokerTemp;
    int foodTemp = receivedFoodTemp;

    // update the smoker actual temperature display
    if (!tempSensorConnected)
    {
      // Show connection error
      lv_label_set_text(lblActualTemp, "NO LINK");
      lv_label_set_text(currentSmokerTemp, "Smoker: NO LINK");
    }
    else if (smokerTemp == -999)
    {
      lv_label_set_text(lblActualTemp, "---°F");
      lv_label_set_text(currentSmokerTemp, "Smoker: ---°F");
    }
    else
    {
      lv_label_set_text_fmt(lblActualTemp, "%d°F", smokerTemp);
      Input = smokerTemp; // Update PID input
      lv_label_set_text_fmt(currentSmokerTemp, "Smoker: %d°F", smokerTemp);
    }

    // update the Food temperature display
    if (!tempSensorConnected)
    {
      // Show connection error
      lv_label_set_text(lblFoodTemp, "NO LINK");
      lv_label_set_text(currentFoodTemp, "Food: NO LINK");
    }
    else if (foodTemp == -999)
    {
      lv_label_set_text(lblFoodTemp, "---°F");
      lv_label_set_text(currentFoodTemp, "Food: ---°F");
    }
    else
    {
      lv_label_set_text_fmt(lblFoodTemp, "%d°F", foodTemp);
      lv_label_set_text_fmt(currentFoodTemp, "Food: %d°F", foodTemp);
    }

    // Update chart only at the specified interval
    if ((millis() - lastChartUpdateTime) > chartUpdateInterval)
    {
      // Only update chart with valid temperature readings
      if (smokerTemp != -999 && tempSensorConnected)
      {
        lv_chart_set_next_value(tempChart, smokerSeries, smokerTemp);
      }
      if (foodTemp != -999 && tempSensorConnected)
      {
        lv_chart_set_next_value(tempChart, foodSeries, foodTemp);
      }
      lastChartUpdateTime = millis();
    }

    Serial.print("Pulses: "); Serial.println(tachPulseCount);
    // get the current RPM and update the display with the value
    unsigned long rpm = (tachPulseCount * 60);  // 2 pulses/rev, 500ms sample: (*120/2 = *60)
    int RPMtemp = map(rpm, 0, 3000, 0, 100);
    lv_bar_set_value(rpmBar, RPMtemp, LV_ANIM_ON);      // display it on the bar
    lv_label_set_text_fmt(rpmPercent, "%d%%", RPMtemp); // and the text
    globalRPM = rpm;
    tachPulseCount = 0;

    lastDisplayUpdateTime = millis(); // reset the current timer time
  }
}

// NOTE: MAX6675 temperature sensor functions have been moved to ESP32-S3 Web Server
// Temperature data is now received via TEMPS: messages from the S3

// start of initialObjects function
// This function creates the display objects and displays them
void initialObjects()
{

  LV_FONT_DECLARE(Antonio_Bold_36_NOHSP);
  LV_FONT_DECLARE(Antonio_Bold_40_NOHSP);
  LV_FONT_DECLARE(Antonio_Bold_60_NOHSP);
  LV_FONT_DECLARE(Arial_60);
  LV_FONT_DECLARE(Arial_Black_60);
  LV_FONT_DECLARE(Arial_Black_12);
  LV_FONT_DECLARE(UpDown120);
  LV_FONT_DECLARE(lv_font_montserrat_14);
  LV_FONT_DECLARE(lv_font_montserrat_20);
  LV_FONT_DECLARE(lv_font_montserrat_26);
  lv_obj_t *scr = lv_screen_active();

  // top swoop
  lv_obj_t *obj0 = lv_obj_create(scr);
  lv_obj_add_style(obj0, &style0, 0);
  lv_obj_set_style_bg_color(obj0, lv_color_make(136, 153, 255), LV_PART_MAIN);
  lv_obj_set_pos(obj0, -10, -40);

  // top row of screen devider
  lv_obj_t *obj1 = lv_obj_create(scr);
  lv_obj_add_style(obj1, &style1, 0);
  lv_obj_set_style_bg_color(obj1, lv_color_make(136, 153, 255), LV_PART_MAIN);
  lv_obj_set_pos(obj1, 80, 128);

  // top left corner
  lv_obj_t *obj2 = lv_obj_create(scr);
  lv_obj_add_style(obj2, &style2, 0);
  lv_obj_set_style_bg_color(obj2, lv_color_make(204, 153, 255), LV_PART_MAIN);
  lv_obj_set_pos(obj2, 0, 0);

  lv_obj_t *obj3 = lv_obj_create(scr);
  lv_obj_add_style(obj3, &styleSeparatorHorizontal, 0);
  lv_obj_set_style_bg_color(obj3, lv_color_black(), LV_PART_MAIN);
  lv_obj_set_pos(obj3, 0, 45);

  lv_obj_t *obj4 = lv_obj_create(scr);
  lv_obj_add_style(obj4, &style3, 0);
  lv_obj_set_style_bg_color(obj4, lv_color_black(), LV_PART_MAIN);
  lv_obj_set_pos(obj4, 90, -17);

  // bottom left swoop
  lv_obj_t *obj5 = lv_obj_create(scr);
  lv_obj_add_style(obj5, &style4, 0);
  lv_obj_set_style_bg_color(obj5, lv_color_make(204, 68, 68), LV_PART_MAIN);
  lv_obj_set_pos(obj5, -10, 140);

  // bottom of screen devider
  lv_obj_t *obj6 = lv_obj_create(scr);
  lv_obj_add_style(obj6, &style5, 0);
  lv_obj_set_style_bg_color(obj6, lv_color_make(204, 68, 68), LV_PART_MAIN);
  lv_obj_set_pos(obj6, 80, 142);

  lv_obj_t *obj7 = lv_obj_create(scr);
  lv_obj_add_style(obj7, &styleSeparatorHorizontal, 0);
  lv_obj_set_style_bg_color(obj7, lv_color_make(0, 0, 0), LV_PART_MAIN);
  lv_obj_set_pos(obj7, 0, 240);

  lv_obj_t *obj8 = lv_obj_create(scr);
  lv_obj_add_style(obj8, &style6, 0);
  lv_obj_set_style_bg_color(obj8, lv_color_make(204, 68, 68), LV_PART_MAIN);
  lv_obj_set_pos(obj8, 0, 245);

  lv_obj_t *obj9 = lv_obj_create(scr);
  lv_obj_add_style(obj9, &styleSeparatorHorizontal, 0);
  lv_obj_set_style_bg_color(obj9, lv_color_make(0, 0, 0), LV_PART_MAIN);
  lv_obj_set_pos(obj9, 0, 385);

  // second from bottom box on left
  lv_obj_t *obj10 = lv_obj_create(scr);
  lv_obj_add_style(obj10, &style7, 0);
  lv_obj_set_style_bg_color(obj10, lv_color_make(255, 136, 0), LV_PART_MAIN);
  lv_obj_set_pos(obj10, 0, 390);
  lv_obj_set_scroll_dir(obj10, LV_DIR_NONE);

  lv_obj_t *obj11 = lv_obj_create(scr);
  lv_obj_add_style(obj11, &style8, 0);
  lv_obj_set_style_bg_color(obj11, lv_color_make(0, 0, 0), LV_PART_MAIN);
  lv_obj_set_pos(obj11, 90, 152);

  lv_obj_t *obj12 = lv_obj_create(scr);
  lv_obj_add_style(obj12, &styleSeparatorHorizontal, 0);
  lv_obj_set_style_bg_color(obj12, lv_color_make(0, 0, 0), LV_PART_MAIN);
  lv_obj_set_pos(obj12, 0, 425);
  lv_obj_set_scroll_dir(obj12, LV_DIR_NONE);

  // bottom left corner box
  lv_obj_t *obj13 = lv_obj_create(scr);
  lv_obj_add_style(obj13, &style9, 0);
  lv_obj_set_style_bg_color(obj13, lv_color_make(255, 153, 102), LV_PART_MAIN);
  lv_obj_set_pos(obj13, 0, 430);

  lv_obj_t *obj14 = lv_obj_create(scr);
  lv_obj_add_style(obj14, &styleSeparatorVertical, 0);
  lv_obj_set_style_bg_color(obj14, lv_color_make(0, 0, 0), LV_PART_MAIN);
  lv_obj_set_pos(obj14, 400, 128);

  lv_obj_t *obj15 = lv_obj_create(scr);
  lv_obj_add_style(obj15, &styleSeparatorVertical, 0);
  lv_obj_set_style_bg_color(obj15, lv_color_make(0, 0, 0), LV_PART_MAIN);
  lv_obj_set_pos(obj15, 450, 128);

  lv_obj_t *obj16 = lv_obj_create(scr);
  lv_obj_add_style(obj16, &styleSeparatorVertical, 0);
  lv_obj_set_style_bg_color(obj16, lv_color_make(0, 0, 0), LV_PART_MAIN);
  lv_obj_set_pos(obj16, 600, 128);
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

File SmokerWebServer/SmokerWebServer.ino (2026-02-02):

/*
 * Smoker Web Server - ESP32-S3
 *
 * This firmware runs on an ESP32-S3 and provides a web interface
 * for the Smoker Controller. It communicates with the main controller
 * (ESP32-P4) via serial connection.
 *
 * Features:
 * - WiFi connectivity with credentials stored in Preferences
 * - AsyncWebServer for REST API
 * - WebSocket for real-time updates
 * - Mobile-friendly web dashboard
 * - WiFi configuration portal
 * - OTA updates via ElegantOTA
 */

#include <Arduino.h>
#include <WiFi.h>
#include <SPI.h>
#include <AsyncTCP.h>
#include <ESPAsyncWebServer.h>
#include <Preferences.h>
#include <ArduinoJson.h>
#include <ESPmDNS.h>
#include <LittleFS.h>
#include "ElegantOTA.h"
#include "webpage.h"
#include "SessionManager.h"

// Serial Communication Settings
#define SERIAL_BAUD 115200
#define CONTROLLER_SERIAL Serial2  // Use Serial2 for communication with controller (independent of USB)
#define CONTROLLER_TX_PIN 17       // TX pin for controller communication
#define CONTROLLER_RX_PIN 18       // RX pin for controller communication
#define SERIAL_BUFFER_SIZE 256

// MAX6675 Temperature Sensor Settings (SPI)
// Using HSPI on ESP32-S3 to avoid conflicts with UART pins
#define SPI_CLK_PIN 12             // SPI Clock
#define SPI_MISO_PIN 13            // SPI MISO (data from sensors)
#define SMOKER_CS_PIN 10           // Chip Select for smoker probe
#define FOOD_CS_PIN 11             // Chip Select for food probe
#define TEMP_READ_INTERVAL 500     // Read sensors every 500ms
#define TEMP_SEND_INTERVAL 500     // Send temps to P4 every 500ms
#define WS_BROADCAST_INTERVAL 1000 // Broadcast state to web clients every 1 second
#define DEBUG_PRINT_INTERVAL 2000  // Print debug info every 2 seconds

// Web Server Settings
#define WEB_SERVER_PORT 80
#define WEBSOCKET_PATH "/ws"

// WiFi Settings
#define WIFI_CONNECT_TIMEOUT 10000  // 10 seconds
#define AP_SSID "SmokerSetup"
#define AP_PASSWORD "smoker123"
#define HOSTNAME "smoker"           // Network hostname (accessible as smoker.local)

// Create objects
AsyncWebServer server(WEB_SERVER_PORT);
AsyncWebSocket ws(WEBSOCKET_PATH);
Preferences preferences;

// Use dedicated HSPI bus for MAX6675 sensors to avoid conflicts
SPIClass hspi(HSPI);

// Serial buffer for controller communication
char serialBuffer[SERIAL_BUFFER_SIZE];
int serialBufferIndex = 0;

// Temperature sensor variables
int localSmokerTemp = 0;       // Temperature read from smoker probe
int localFoodTemp = 0;         // Temperature read from food probe
unsigned long lastTempReadTime = 0;

// Temperature calibration offsets (stored in NVram)
int smokerTempOffset = 0;      // Calibration offset for smoker probe (degrees F)
int foodTempOffset = 0;        // Calibration offset for food probe (degrees F)
unsigned long lastTempSendTime = 0;
unsigned long lastWsBroadcastTime = 0;
unsigned long lastDebugPrintTime = 0;

// Temperature History Settings
#define HISTORY_SIZE 60           // 60 data points = 2 hours at 2-minute intervals
#define HISTORY_INTERVAL 120000   // 2 minutes in milliseconds

// Temperature history arrays
int smokerTempHistory[HISTORY_SIZE];
int foodTempHistory[HISTORY_SIZE];
int historyIndex = 0;
int historyCount = 0;  // Number of valid data points
unsigned long lastHistoryUpdate = 0;

// Current smoker state (parsed from DATA messages)
struct SmokerState {
  int smokerTemp = 0;
  int foodTemp = 0;
  int setTemp = 225;
  int rpm = 0;
  int pwm = 0;
  bool fanOn = false;
  unsigned long timerMs = 0;
  float Kp = 7.0;
  float Ki = 0.0;
  float Kd = 0.2;
  unsigned long lastUpdate = 0;
} smokerState;

// WiFi credentials
String wifiSSID = "";
String wifiPassword = "";
String hostname = HOSTNAME;  // Default hostname, can be changed via web interface
bool wifiConnected = false;
bool apMode = false;

// Controller connection timeout (if no data received for 5 seconds, assume disconnected)
#define CONTROLLER_TIMEOUT 5000

// Function declarations
void setupWiFi();
void setupWebServer();
void setupWebSocket();
void setupTemperatureSensors();
void readTemperatureSensors();
void sendTemperaturesToController();
float readMAX6675(int csPin);
int readSmokerTemperature();
int readFoodTemperature();
void checkControllerSerial();
void parseDataMessage(char* data);
void broadcastState();
void handleWebSocketMessage(void *arg, uint8_t *data, size_t len);
void onWsEvent(AsyncWebSocket *server, AsyncWebSocketClient *client,
               AwsEventType type, void *arg, uint8_t *data, size_t len);
String getStateJson();
String getHistoryJson();
void sendCommandToController(const char* cmd);
void recordTemperatureHistory();
void initializeHistory();

void setup() {
  // Initialize USB serial for debugging
  Serial.begin(115200);
  delay(2000);  // Longer delay for USB CDC to enumerate

  Serial.println();
  Serial.println("*** BOOT ***");  // Very first message
  Serial.flush();  // Force output
  delay(100);

  Serial.println("========================================");
  Serial.println("    Smoker Web Server - ESP32-S3");
  Serial.println("========================================");
  Serial.println();

  // Initialize MAX6675 temperature sensors FIRST (before Serial1)
  setupTemperatureSensors();

  // Initialize serial for controller communication on dedicated pins
  Serial.print("Initializing controller serial on TX:");
  Serial.print(CONTROLLER_TX_PIN);
  Serial.print(" RX:");
  Serial.println(CONTROLLER_RX_PIN);
  CONTROLLER_SERIAL.begin(SERIAL_BAUD, SERIAL_8N1, CONTROLLER_RX_PIN, CONTROLLER_TX_PIN);
  delay(100);

  // Initialize preferences for WiFi storage
  preferences.begin("smoker", false);
  wifiSSID = preferences.getString("ssid", "");
  wifiPassword = preferences.getString("password", "");
  hostname = preferences.getString("hostname", HOSTNAME);

  // Load temperature calibration offsets from NVram
  smokerTempOffset = preferences.getInt("smokerOffset", 0);
  foodTempOffset = preferences.getInt("foodOffset", 0);
  Serial.print("Loaded calibration offsets - Smoker: ");
  Serial.print(smokerTempOffset);
  Serial.print("F, Food: ");
  Serial.print(foodTempOffset);
  Serial.println("F");

  // Initialize temperature history
  initializeHistory();

  // Initialize session manager (LittleFS for persistent session storage)
  if (!sessionManager.begin()) {
    Serial.println("Warning: Session recording disabled - LittleFS init failed");
  }

  // Setup WiFi
  setupWiFi();

  // Setup web server and WebSocket
  setupWebSocket();
  setupWebServer();
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

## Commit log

2026-02-02 Fix typos in README.md
    Corrected typos in the README regarding the Arduino Maker Workshop and build profiles.
2026-02-02 Fix typos in README.md
    Corrected typos in the README regarding Arduino Maker Workshop and project details.
2026-02-03 Adding PID details
2026-02-03 Add device order link for ESP32-P4
    Added a link to the device order page for the ESP32-P4.
2026-02-03 Fix typo in README regarding fan control
2026-02-03 Update README to clarify servo control functionality
    Clarified the functionality of the system regarding fan and servo control for passive fire systems.
2026-02-03 Adding 3d models
    [Housing.3mf, Large Clip.3mf, PCB Mount.3mf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]
2026-02-03 Update README with printing and PCB details
    Added details about printing process and PCB fabrication.
2026-02-03 Update display unit description in README
    Clarified the display unit's model name and added context about potential modifications for controlling a ball valve.
2026-02-04 Update README with Fusion file details
    Added information about the 'Smoker Housing.f3d' file for modifications.

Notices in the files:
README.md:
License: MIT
